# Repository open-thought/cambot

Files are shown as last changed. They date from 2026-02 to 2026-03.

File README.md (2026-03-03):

# CamBot

<p align="center">
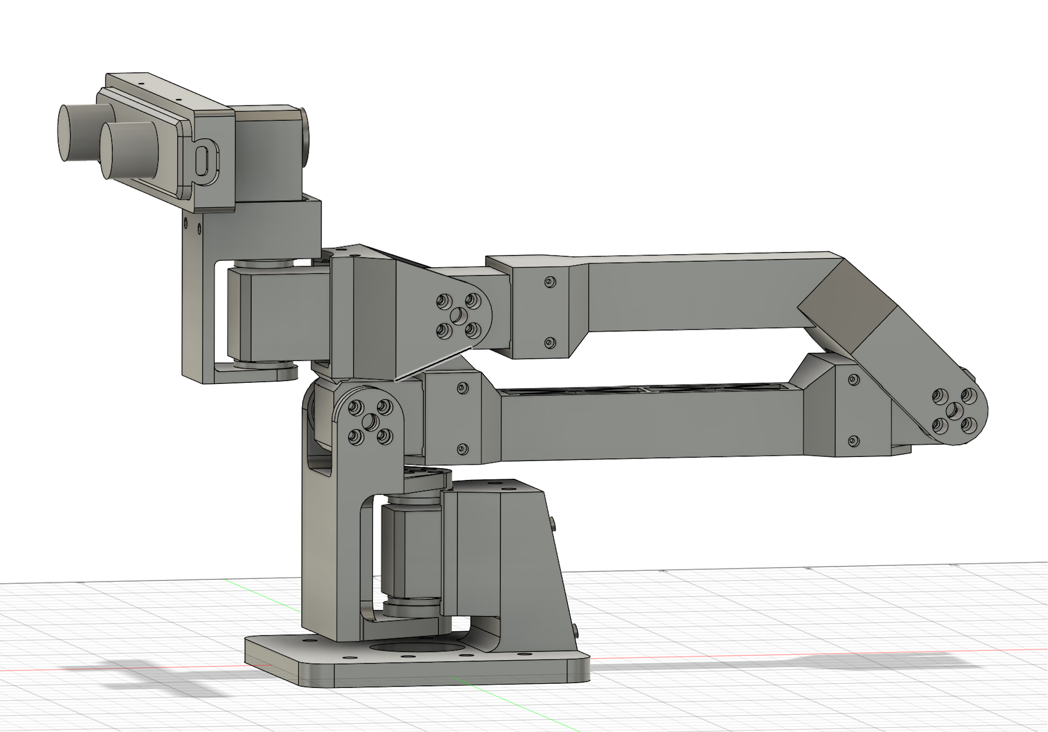
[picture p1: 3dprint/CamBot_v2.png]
CamBot
  
</p>

6-DOF camera arm for stereo vision, built with Feetech STS3215 servos and a ZED Mini stereo camera. Includes a VR teleop system using WebXR for real-time head tracking from any compatible VR headset (tested with Meta Quest 3).

**[Build & Assembly Guide](docs/BUILD_GUIDE.md)**

## Hardware

- **Body:** 7x 3D printed parts (PLA)
- **Servos:** 6x Feetech STS3215 (serial bus)
- **Camera:** [StereoLabs ZED Mini](https://www.stereolabs.com/en-de/store/products/zed-mini) (63mm baseline stereo)
- **Joints:** base_yaw, shoulder_pitch, elbow_pitch, wrist_pitch, wrist_yaw, camera_roll

## Project Structure

```
cambot/
  servo/              Shared servo communication layer
    constants.py      Register addresses, motor config, conversions
    protocol.py       Wire protocol (decode/encode, connect, EPROM helpers)
    controller.py     CamBotServo class, save/load calibration
  teleop/             VR teleop application
    app.py            Main entry point (TeleHead control loop)
    server.py         HTTPS + WebSocket server (aiohttp)
    ik_solver.py      IK solver (ikpy + URDF)
    capture.py        ZED Mini / fallback camera capture
    webrtc.py         WebRTC H.264 video track
    client/           WebXR stereo viewer (Three.js)
  tools/              CLI diagnostic and setup tools
    fix_servo_ids.py  Scan and assign servo IDs
    read_params.py    Register dump / read / write
    set_pid.py        Write tested PID parameters to servos
    debug_control.py  Debug TUI with IK visualization
    pid_tuning.py     PID auto-tuner
    visualize_urdf.py URDF visualization (viser)
calibration/          Saved positions and calibration data
urdf/                 URDF model and STL meshes
3dprint/              STL files for 3D printing (mm scale)
docs/                 Build guide, datasheets, and manuals
```

## Setup

Tested on Linux (Ubuntu 24.04). Requires [uv](https://docs.astral.sh/uv/getting-started/installation/) for Python environment and dependency management.

```bash
uv pip install -e .              # install cambot package (editable)
uv pip install -e ".[viz]"       # + URDF visualization (viser)
```

For ZED Mini support, install the [ZED SDK](https://www.stereolabs.com/en-de/developers/release) and the [ZED Python API](https://www.stereolabs.com/docs/development/python/install) (not available on PyPI).

## VR Teleop

Stream stereo video to a WebXR-compatible VR headset and control the robot arm with head tracking:

```bash
./run_teleop.sh                              # full mode
./run_teleop.sh --no-robot                   # camera streaming only
./run_teleop.sh --no-camera                  # robot control only
./run_teleop.sh --no-zed                     # use fallback camera
```

<details>
<summary>All options</summary>

```
usage: cambot-teleop [-h] [--port PORT] [--no-robot] [--no-camera] [--no-zed]
                     [--smoothing SMOOTHING] [--rate RATE]
                     [--max-joint-vel MAX_JOINT_VEL]
                     [--position-scale POSITION_SCALE]
                     [--max-pos-delta MAX_POS_DELTA]
                     [--workspace-bounds WORKSPACE_BOUNDS]
                     [--watchdog-timeout WATCHDOG_TIMEOUT]
                     [--resolution {vga,720p,1080p,2k}]
                     [--camera-fps CAMERA_FPS] [--jpeg-quality JPEG_QUALITY]
                     [--no-webrtc] [--server-port SERVER_PORT]
                     [--save-home] [--save-resting]
                     [--home HOME] [--resting RESTING]

  --port PORT               Robot serial port (default: /dev/ttyACM0)
  --no-robot                Run without robot
  --no-camera               Run without camera
  --no-zed                  Use fallback camera instead of ZED SDK
  --smoothing SMOOTHING     EMA smoothing (0=none, 0.99=max)
  --rate RATE               Control loop Hz
  --max-joint-vel MAX_JOINT_VEL
                            Max joint velocity rad/s (default: 20.0)
  --position-scale POSITION_SCALE
                            Scale factor for VR head translation (default: 1.0)
  --max-pos-delta MAX_POS_DELTA
                            Safety sphere radius in meters (default: 0.15, 0=disable)
  --workspace-bounds WORKSPACE_BOUNDS
                            Bounding box 'xmin,xmax,ymin,ymax,zmin,zmax' (meters)
  --watchdog-timeout WATCHDOG_TIMEOUT
                            Return to home after N seconds without VR pose (default: 3.0, 0=disable)
  --resolution {vga,720p,1080p,2k}
                            Camera resolution (default: 720p)
  --camera-fps CAMERA_FPS   Camera FPS (default: auto based on resolution)
  --jpeg-quality JPEG_QUALITY
                            JPEG encoding quality 1-100 (default: 85)
  --no-webrtc               Disable WebRTC, use WebSocket JPEG only
  --server-port SERVER_PORT HTTPS server port (default: 8080)
  --save-home               Save current position as home and exit
  --save-resting            Save current position as resting and exit
  --home HOME               Path to home_position.json
  --resting RESTING         Path to resting_position.json
```

</details>

The server prints an HTTPS URL in the terminal — open it in the headset browser, then enter VR.

```
============================================================
  CamBot TeleHead: https://192.168.0.103:8080
  Robot: connected on /dev/ttyACM0
  Camera: ZED Mini 720p@60fps q85
  WebRTC: enabled (H.264)
  Safety: watchdog=3.0s

  Press ENTER to home (capture neutral head position).
  Press P+ENTER to toggle position tracking (default: OFF).
  Press L+ENTER to lock/unlock robot (pause control).
  Press Ctrl+C to quit.
============================================================
```

### Controls

**Terminal (host PC):**

| Key | Action |
|-----|---|
| Enter | Home robot and calibrate neutral head pose |
| P + Enter | Toggle position tracking (orientation-only ↔ full 6-DOF) |
| L + Enter | Toggle pause (lock robot in place) |
| Ctrl+C | Quit (returns robot to resting pose) |

**VR controllers (WebXR gamepad):**

| Button | Action |
|---|---|
| A / X | Home and calibrate (soft recalibrate if already homed) |
| B / Y | Toggle position tracking |
| Right squeeze | Toggle pause |
| Left squeeze | Toggle HUD overlay |
| Right thumbstick click | Cycle resolution (VGA → 720p → 1080p → 2K) |
| Left thumbstick click | Toggle transport (WebRTC H.264 ↔ WebSocket JPEG) |

The robot automatically pauses and returns to home when the headset is removed, and resumes when put back on.

### Safety features

Position tracking mode has built-in safety limits:

- **Position delta sphere** (default 15cm): limits end-effector displacement from home. `--max-pos-delta 0.20` for 20cm, or `--max-pos-delta 0` to disable.
- **Workspace bounding box**: hard axis-aligned limits in robot frame. `--workspace-bounds xmin,xmax,ymin,ymax,zmin,zmax` (meters). Auto-disables the default sphere.
- **Pose watchdog** (default 3s): smoothly returns to home if VR data stops (headset removed, connection lost). `--watchdog-timeout 5.0` or `--watchdog-timeout 0` to disable.

Additional safety: EMA smoothing, velocity clamping (20 rad/s), FK validation, torque limiting (90%).

## Tools

All tools have shell script wrappers in the project root:

```bash
./run_fix_servo_ids.sh           # scan/set servo IDs
./run_read_params.sh             # register dump
./run_set_pid.sh                 # write tested PID values to servos
./run_debug_control.sh           # debug TUI with IK
./run_pid_tuning.sh              # PID auto-tuner
./run_visualize_urdf.sh          # URDF 3D viewer (browser)
```

Or run directly via entry points: `uv run cambot-debug-control`

## Dependencies

- Python 3.12+
- `feetech-servo-sdk` (servo communication, imported as `scservo_sdk`)
- `numpy`, `scipy`, `ikpy` (IK solver)
- `aiohttp`, `opencv-python`, `aiortc` (teleop server + video + WebRTC)
- Optional: `pyzed` (ZED SDK), `viser` (URDF viz)

## Acknowledgements

- The [TRLC-DK1 Leader](https://github.com/robot-learning-co/trlc-dk1) arm design by Robot Learning Co. served as inspiration for CamBot.
- The [SO-ARM100](https://github.com/TheRobotStudio/SO-ARM100) project by The Robot Studio — CamBot uses the same servo platform and controller board.
- Special thanks to [Autodesk](https://www.autodesk.com/) for providing Fusion for personal use.
- Special thanks to [FeeTech](https://www.feetechrc.com/) for their great servo motors — I wish I already had these as a kid. ;-)

## License

Apache 2.0 — see [LICENSE](LICENSE) for details.

If you build a CamBot or use this project in your work, I'd love to hear about it! A mention or link back is always appreciated. And if you get your CamBot running, please share a photo or video on [X/Twitter](https://x.com) — tag [@neurosp1ke](https://x.com/neurosp1ke) so I can see it!

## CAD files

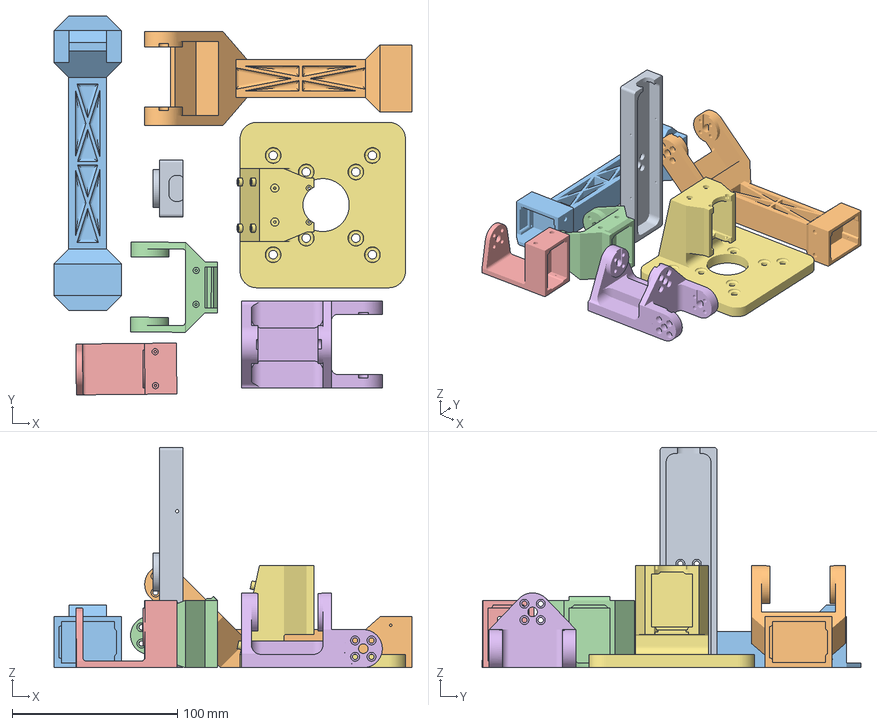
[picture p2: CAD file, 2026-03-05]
3dprint/CamBot_v2.3mf
216.4 x 229.1 x 133.2 mm
CamBot_ZedMiniMount_OffCenter.stl
CamBot_Link3_Thin.stl
CamBot_Link2_Thin.stl
CamBot_Link4.stl
CamBot_Link5.stl
CamBot_Link1.stl
CamBot_Baseplate.stl

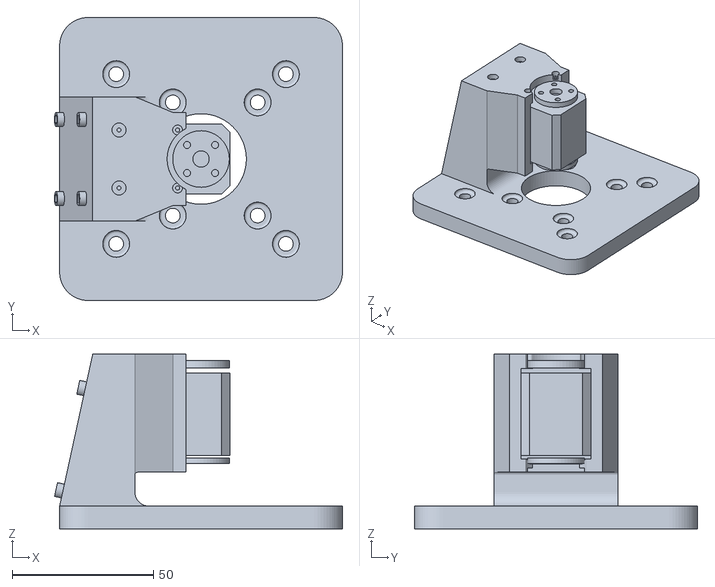
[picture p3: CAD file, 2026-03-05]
urdf/meshes/Baseplate.stl
101.8 x 100.0 x 61.7

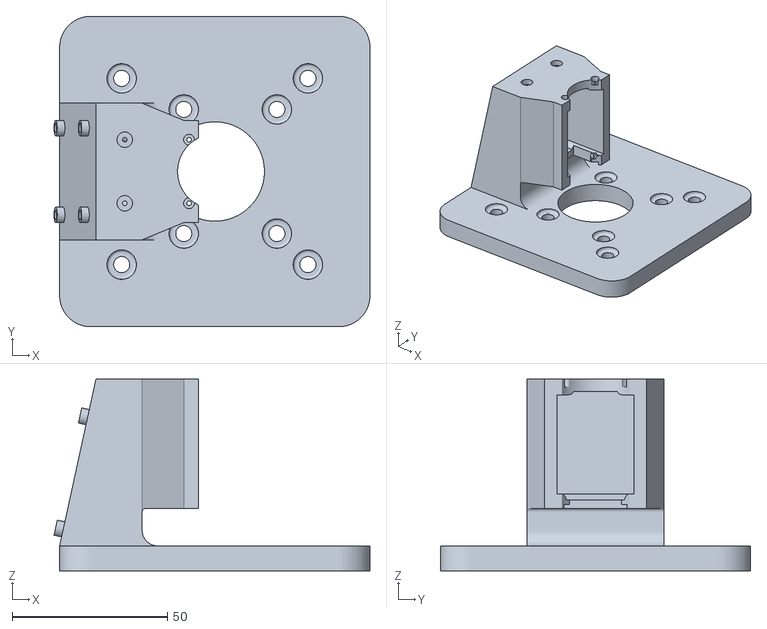
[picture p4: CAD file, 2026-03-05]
3dprint/CamBot_Baseplate.stl
101.8 x 100.0 x 61.7

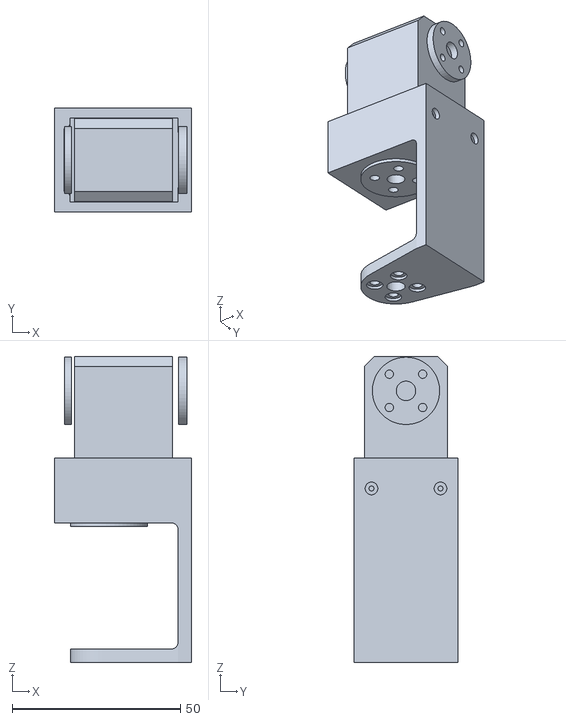
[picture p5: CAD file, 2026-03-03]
urdf/meshes/Link5.stl
40.7 x 30.8 x 90.9

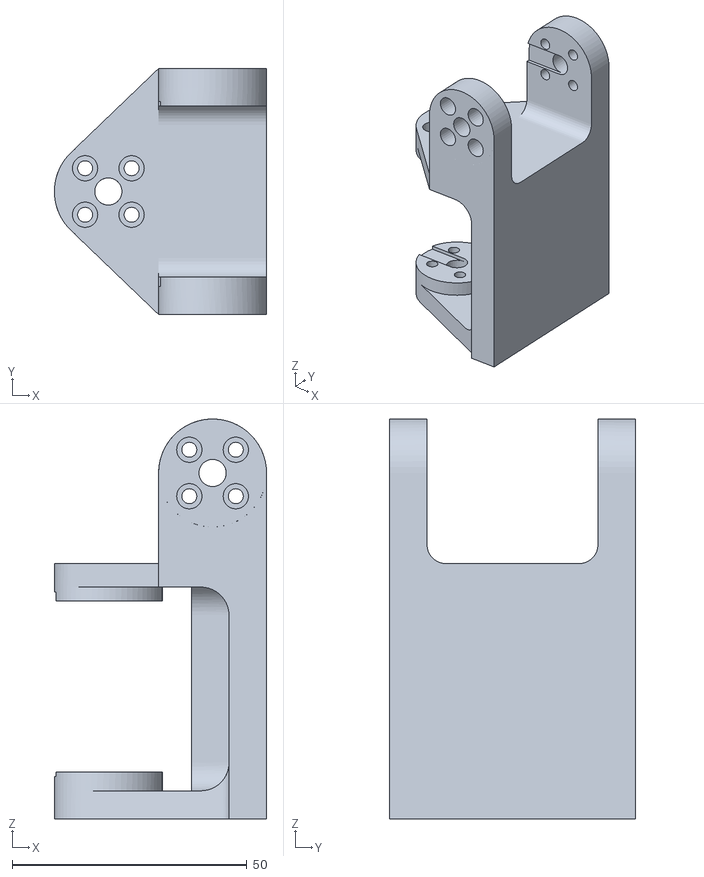
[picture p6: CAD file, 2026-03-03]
3dprint/CamBot_Link1.stl
45.2 x 52.4 x 85.2

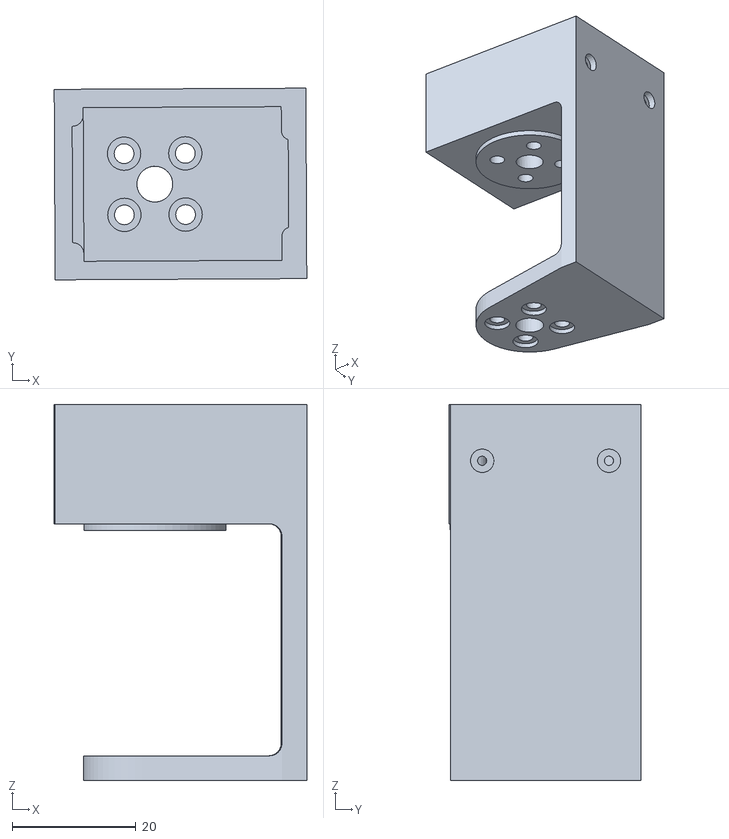
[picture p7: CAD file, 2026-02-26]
3dprint/CamBot_Link5.stl
40.9 x 31.0 x 60.8

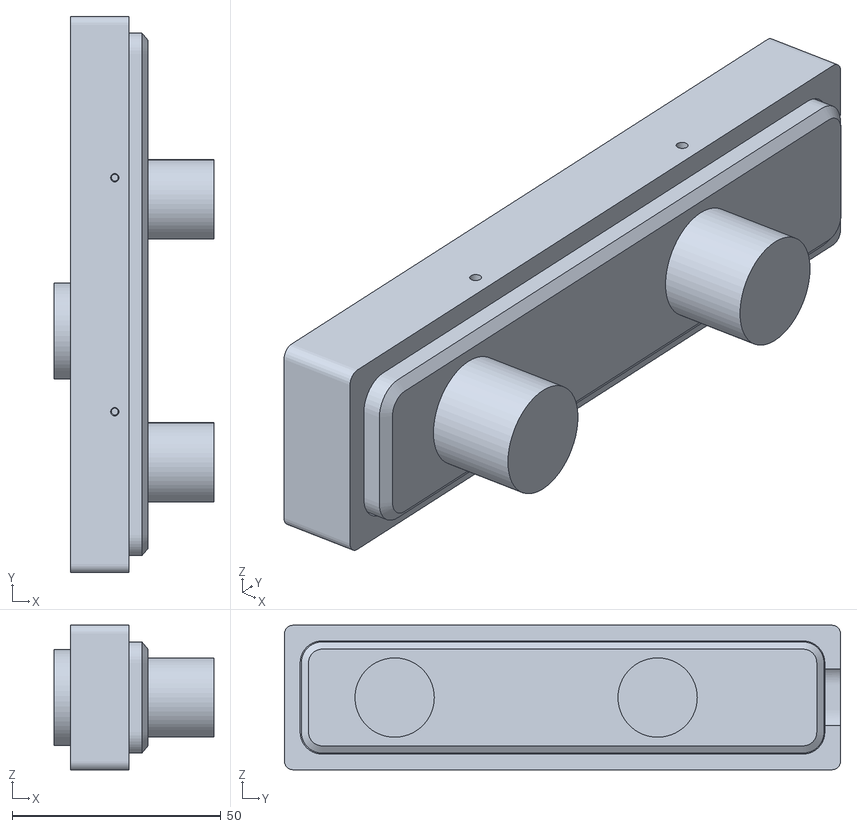
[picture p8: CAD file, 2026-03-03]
urdf/meshes/ZedMiniMount.stl
38.3 x 133.2 x 34.6

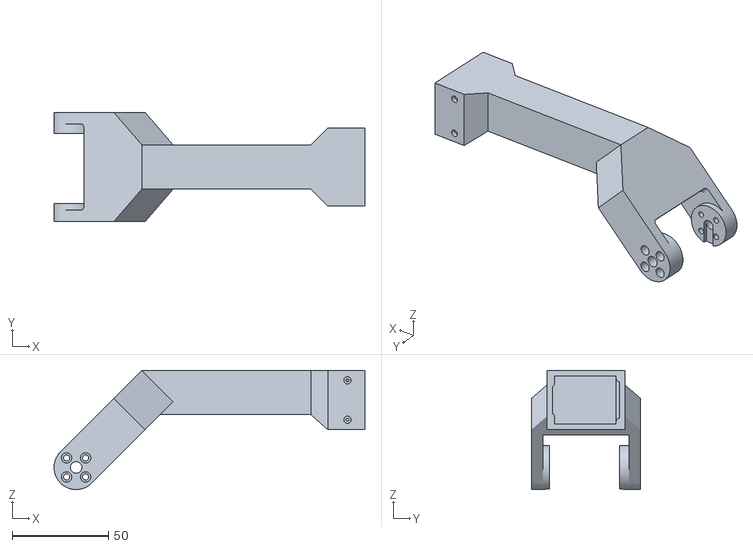
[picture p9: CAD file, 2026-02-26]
3dprint/CamBot_Link3.stl
161.6 x 56.7 x 61.9

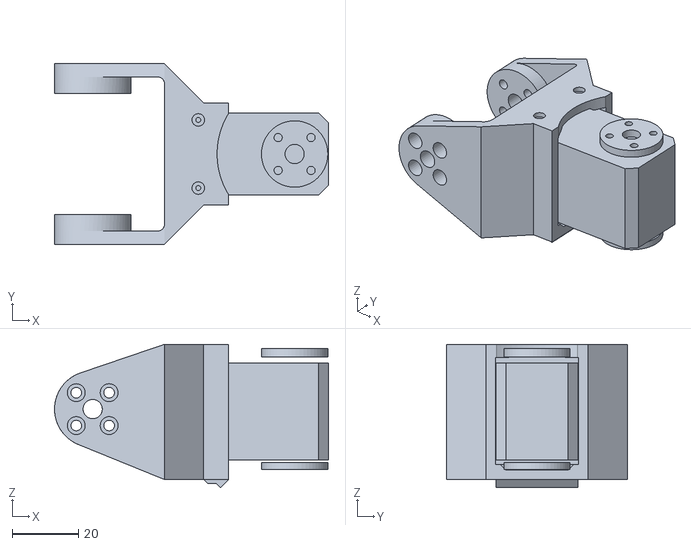
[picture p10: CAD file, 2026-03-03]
urdf/meshes/Link4.stl
82.5 x 54.4 x 43.1

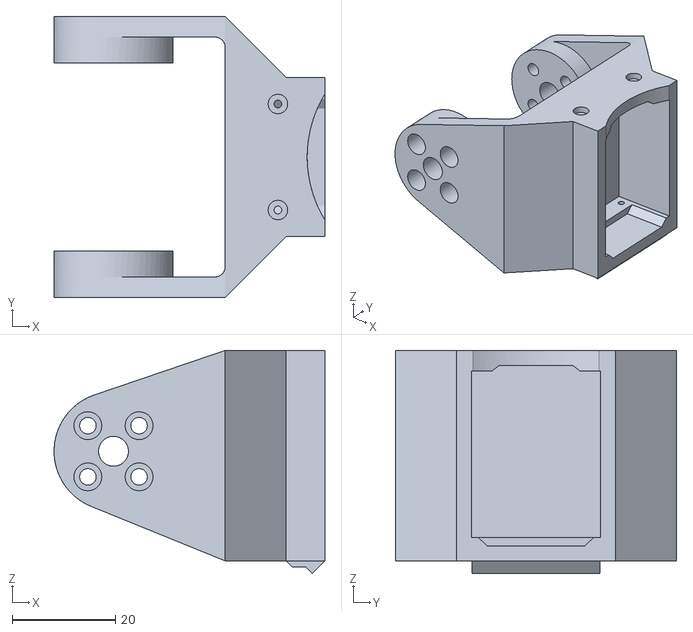
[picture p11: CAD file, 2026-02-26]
3dprint/CamBot_Link4.stl
52.4 x 54.4 x 43.1

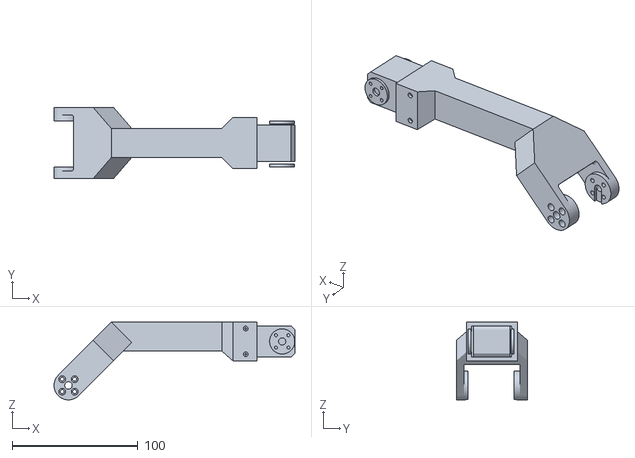
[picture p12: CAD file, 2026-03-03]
urdf/meshes/Link3.stl
191.7 x 56.7 x 61.9

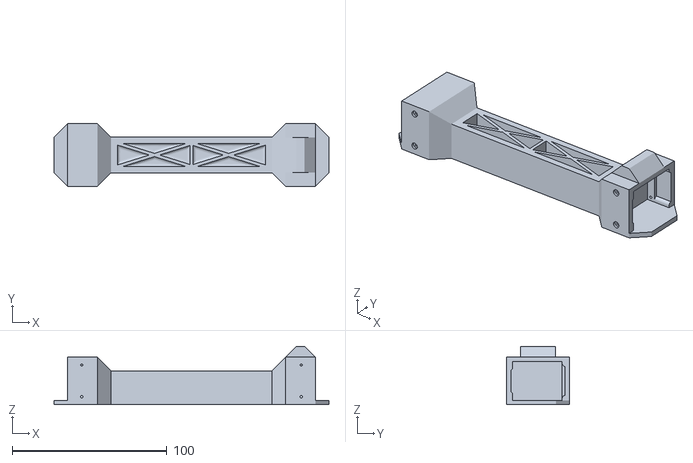
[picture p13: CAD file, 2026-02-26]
3dprint/CamBot_Link2.stl
177.9 x 40.7 x 37.8

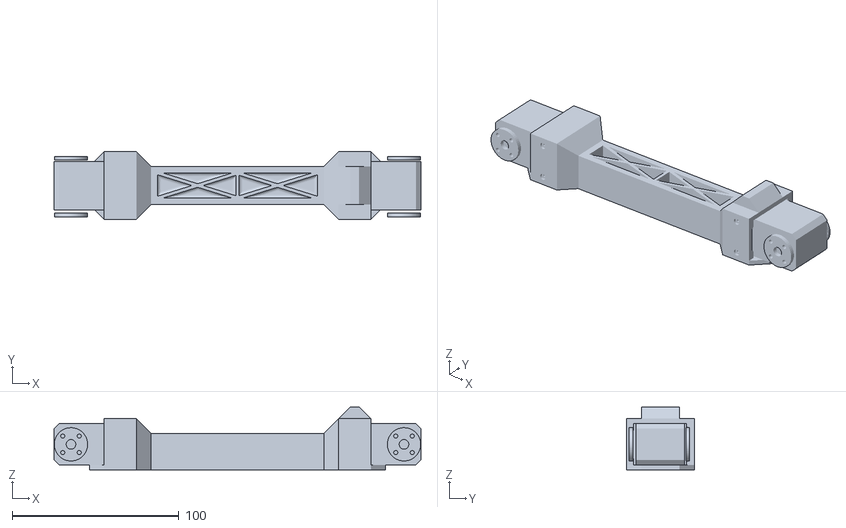
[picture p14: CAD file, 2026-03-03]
urdf/meshes/Link2.stl
220.4 x 40.7 x 37.8

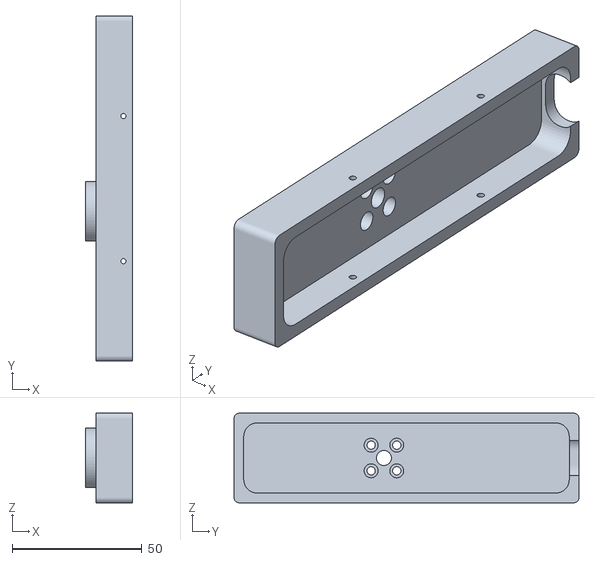
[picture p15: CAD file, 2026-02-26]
3dprint/CamBot_ZedMiniMount.stl
18.0 x 133.2 x 34.6

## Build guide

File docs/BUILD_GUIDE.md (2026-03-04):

# CamBot Build & Assembly Guide

## Parts List

| Part | Qty | Notes |
|---|-----|---|
| Feetech STS3215-C001 7.4V (1:345) | 3 | base_yaw, shoulder_pitch, elbow_pitch — high torque for structural joints |
| Feetech STS3215-C046 7.4V (1:147) | 3 | wrist_pitch, wrist_yaw, camera_roll — faster for orientation changes |
| Waveshare Bus Servo Adapter (A) | 1 | USB serial bus controller ([Amazon](https://amzn.eu/d/04b0u8LV)) |
| LEICKE Power supply 5V 4A 20W | 1 | Powers servo bus via adapter ([Amazon](https://amzn.eu/d/03hZC3xp)) |
| StereoLabs ZED Mini | 1 | USB 3.1 stereo camera, 63mm baseline ([Store](https://www.stereolabs.com/en-de/store/products/zed-mini)) |
| 3D printed parts | 7 | See printing section below |

For sourcing servos, the bus controller, power supply, USB cables, and screwdriver set, see the [SO-ARM100 repository](https://github.com/TheRobotStudio/SO-ARM100) — CamBot uses the same servo platform.

## 3D Printing

**Printer:** Bambu Lab A1 ([bambulab.com](https://bambulab.com/en/a1)) or similar FDM printer

**Filament:** eSUN PLA Basic 1.75mm (any rigid PLA works)

**Settings:**
- 25% infill (gyroid or grid)
- Tree supports (auto)
- 4 wall loops for rigidity

**Files:**
- Full Bambu Studio plate: `3dprint/CamBot_v2.3mf`
- Individual STLs in `3dprint/`:
  - `CamBot_Baseplate.stl`
  - `CamBot_Link1.stl` through `CamBot_Link5.stl`
  - `CamBot_ZedMiniMount.stl`

## Motor Configuration (Before Assembly)

### 1. Set Motor IDs

Connect only **one motor at a time** to the bus and assign IDs 1-6:

```bash
./run_fix_servo_ids.sh --set-id 1   # base_yaw
./run_fix_servo_ids.sh --set-id 2   # shoulder_pitch
./run_fix_servo_ids.sh --set-id 3   # elbow_pitch
./run_fix_servo_ids.sh --set-id 4   # wrist_pitch
./run_fix_servo_ids.sh --set-id 5   # wrist_yaw
./run_fix_servo_ids.sh --set-id 6   # camera_roll
```

### 2. Set PID & Torque Parameters

Connect all motors to the bus, then write the tested PID and torque values:

```bash
./run_set_pid.sh            # write recommended PID + torque settings
./run_set_pid.sh --dry-run  # preview values without writing
```

The recommended PID values (factory defaults are P=16, D=32, I=0):

| Joint | ID | Servo | P | D | I |
|---|---:|---|--:|--:|--:|
| base_yaw | 1 | C001 (1:345) | 24 | 48 | 0 |
| shoulder_pitch | 2 | C001 (1:345) | 32 | 16 | 0 |
| elbow_pitch | 3 | C001 (1:345) | 64 | 32 | 0 |
| wrist_pitch | 4 | C046 (1:147) | 48 | 32 | 0 |
| wrist_yaw | 5 | C046 (1:147) | 32 | 32 | 0 |
| camera_roll | 6 | C046 (1:147) | 25 | 32 | 0 |

These values were tuned for smooth VR teleop tracking. The C001 high-torque joints (base, shoulder, elbow) need different gains than the C046 fast joints (wrist, camera) due to their different gear ratios.

The script also writes torque protection settings:
- **Overload_Torque = 95** for motors 1-5 (factory default is 25). The factory value is too low — load-bearing joints (especially shoulder_pitch) constantly fight gravity, causing the servo to trip overload protection during normal operation. Setting it to 95 allows up to 95% of maximum torque before protection activates.
- **Max_Torque_Limit = 500** (50%) for camera_roll — no need for full torque on camera rotation.

A full reference dump of all register values is available in [`docs/reference_params.txt`](reference_params.txt).

### 3. Verify

```bash
./run_read_params.sh        # full register dump — check PID, ID, mode
```

## Assembly

1. Label each servo with its ID (1-6) before assembly — they are indistinguishable once mounted.
2. Assemble from base to camera: Baseplate -> Link1 -> Link2 -> Link3 -> Link4 -> Link5 -> ZedMiniMount.
3. Route servo cables through the links. Daisy-chain all servos on the same bus.
4. Apply medium-strength threadlocker (e.g. Loctite 243) to the servo flange screws — vibrations will loosen them over time.
5. Mount the ZED Mini camera on the top link using the printed mount.

## Calibration

After assembly, calibrate the two reference poses:

### 1. URDF Zero (Resting) Pose

Position the arm in the resting pose shown below. This defines the URDF zero reference for the IK solver.

CamBot URDF zero pose

```bash
./run_teleop.sh --save-resting
# or use debug_control: ./run_debug_control.sh then press Z
```

### 2. Home Pose

Move the arm to the starting camera position for VR teleop (where the camera faces forward at a comfortable viewing angle). The photo below shows an example home pose used during testing:

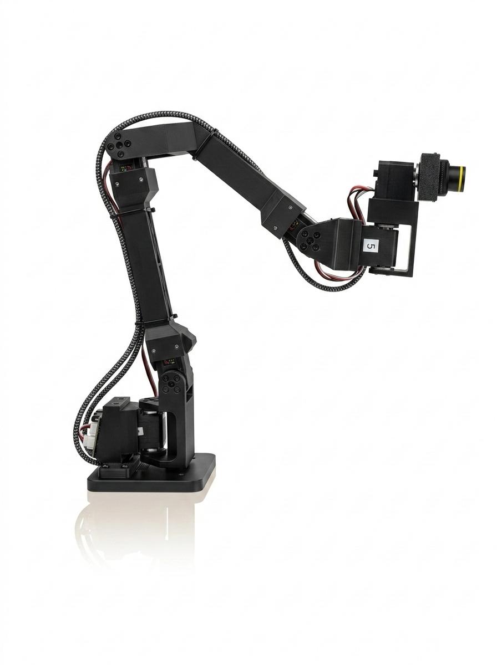
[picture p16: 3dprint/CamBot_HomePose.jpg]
CamBot home pose example


```bash
./run_teleop.sh --save-home
# or use debug_control: ./run_debug_control.sh then press H
```

## Running

```bash
./run_teleop.sh                    # full VR teleop (robot + camera + WebRTC)
./run_teleop.sh --no-robot         # camera streaming only (no servos)
./run_teleop.sh --no-camera        # robot control only (no video)
./run_teleop.sh --no-zed           # use fallback USB camera
```

Open the displayed HTTPS URL in the headset browser, enter VR, then press Enter in the terminal to calibrate the neutral head position.

## PID Tuning (Optional, Advanced)

The default PID values set by `run_set_pid.sh` work well for general use. If you want to tune for your specific build (different filament or payload), there are two approaches:

### Interactive tuning with debug_control

```bash
./run_debug_control.sh
```

Switch to PID mode (press `P` in the TUI) to adjust P, D, and I gains per joint in real time while watching the servo response. This is the best way to get a feel for how each parameter affects tracking behavior — you can command step moves and immediately see overshoot, settling time, and steady-state error.

### Automated tuning (experimental)

> **Warning:** Automated tuning is experimental and puts the hardware under stress. It commands rapid step moves at various gain levels, which can cause jerky motion and high transient loads on the servos and 3D printed parts. Supervise the robot during tuning and be ready to kill the script if anything sounds or looks wrong.

```bash
uv run cambot-pid-tuning --capture-poses           # capture test poses first
uv run cambot-pid-tuning --joints shoulder_pitch    # tune a specific joint
uv run cambot-pid-tuning --verbose                  # tune all joints with detailed output
uv run cambot-pid-tuning --restore-factory          # reset to factory PID defaults
```

Runs automated step-response tests and searches for gains that minimize overshoot and settling time.

If you find better PID values for your build, please share them by [opening a GitHub issue](https://github.com/open-thought/cambot/issues).

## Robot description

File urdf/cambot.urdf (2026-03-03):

<?xml version="1.0" encoding="utf-8"?>
<robot name="CamBot">

  <!-- ==================== Materials ==================== -->
  <material name="dark_grey">
    <color rgba="0.3 0.3 0.3 1.0"/>
  </material>
  <material name="light_grey">
    <color rgba="0.6 0.6 0.6 1.0"/>
  </material>
  <material name="black">
    <color rgba="0.1 0.1 0.1 1.0"/>
  </material>

  <!-- ==================== Links ==================== -->

  <!-- Baseplate: world origin (0, 0, 0) -->
  <link name="base_link">
    <visual>
      <origin xyz="0 0 0" rpy="0 0 0"/>
      <geometry>
        <mesh filename="meshes/Baseplate.stl"/>
      </geometry>
      <material name="dark_grey"/>
    </visual>
  </link>

  <!-- Link1: world pos (0, 0, 0.03820) -->
  <link name="link1">
    <visual>
      <origin xyz="0 0 -0.03820" rpy="0 0 0"/>
      <geometry>
        <mesh filename="meshes/Link1.stl"/>
      </geometry>
      <material name="light_grey"/>
    </visual>
  </link>

  <!-- Link2: world pos (0.02220, 0, 0.08370) -->
  <link name="link2">
    <visual>
      <origin xyz="-0.02220 0 -0.08370" rpy="0 0 0"/>
      <geometry>
        <mesh filename="meshes/Link2.stl"/>
      </geometry>
      <material name="dark_grey"/>
    </visual>
  </link>

  <!-- Link3: world pos (-0.17780, 0, 0.08370) -->
  <link name="link3">
    <visual>
      <origin xyz="0.17780 0 -0.08370" rpy="0 0 0"/>
      <geometry>
        <mesh filename="meshes/Link3.stl"/>
      </geometry>
      <material name="light_grey"/>
    </visual>
  </link>

  <!-- Link4: world pos (-0.00780, 0, 0.11870) -->
  <link name="link4">
    <visual>
      <origin xyz="0.00780 0 -0.11870" rpy="0 0 0"/>
      <geometry>
        <mesh filename="meshes/Link4.stl"/>
      </geometry>
      <material name="dark_grey"/>
    </visual>
  </link>

  <!-- Link5: world pos (0.05300, 0, 0.11870) -->
  <link name="link5">
    <visual>
      <origin xyz="-0.05300 0 -0.11870" rpy="0 0 0"/>
      <geometry>
        <mesh filename="meshes/Link5.stl"/>
      </geometry>
      <material name="light_grey"/>
    </visual>
  </link>

  <!-- ZED Mini mount: world pos (0.05800, 0, 0.17720) -->
  <link name="zed_mini_mount">
    <visual>
      <origin xyz="-0.05800 0 -0.17720" rpy="0 0 0"/>
      <geometry>
        <mesh filename="meshes/ZedMiniMount.stl"/>
      </geometry>
      <material name="black"/>
    </visual>
  </link>

  <!-- Camera links (no visual geometry, just reference frames) -->
  <link name="right_camera_link"/>
  <link name="left_camera_link"/>
  <link name="right_camera_optical_frame"/>
  <link name="left_camera_optical_frame"/>

  <!-- ==================== Joints ==================== -->

  <!-- Joint 1: base_link -> link1, vertical rotation (Z axis) -->
  <!-- Relative: (0, 0, 0.03820) - (0, 0, 0) = (0, 0, 0.03820) -->
  <joint name="base_yaw" type="revolute">
    <parent link="base_link"/>
    <child link="link1"/>
    <origin xyz="0 0 0.03820" rpy="0 0 0"/>
    <axis xyz="0 0 -1"/>
    <limit lower="-1.2747" upper="1.3346" effort="1.5" velocity="3.0"/>
  </joint>

  <!-- Joint 2: link1 -> link2, horizontal rotation (Y axis) -->
  <!-- Relative: (0.02220, 0, 0.08370) - (0, 0, 0.03820) = (0.02220, 0, 0.04550) -->
  <joint name="shoulder_pitch" type="revolute">
    <parent link="link1"/>
    <child link="link2"/>
    <origin xyz="0.02220 0 0.04550" rpy="0 0 0"/>
    <axis xyz="0 -1 0"/>
    <limit lower="-3.4392" upper="0.0936" effort="1.5" velocity="3.0"/>
  </joint>

  <!-- Joint 3: link2 -> link3, horizontal rotation (Y axis) -->
  <!-- Relative: (-0.17780, 0, 0.08370) - (0.02220, 0, 0.08370) = (-0.20000, 0, 0) -->
  <joint name="elbow_pitch" type="revolute">
    <parent link="link2"/>
    <child link="link3"/>
    <origin xyz="-0.20000 0 0" rpy="0 0 0"/>
    <axis xyz="0 1 0"/>
    <limit lower="-4.2599" upper="0.0353" effort="1.5" velocity="3.0"/>
  </joint>

  <!-- Joint 4: link3 -> link4, horizontal rotation (Y axis) -->
  <!-- Relative: (-0.00780, 0, 0.11870) - (-0.17780, 0, 0.08370) = (0.17000, 0, 0.03500) -->
  <joint name="wrist_pitch" type="revolute">
    <parent link="link3"/>
    <child link="link4"/>
    <origin xyz="0.17000 0 0.03500" rpy="0 0 0"/>
    <axis xyz="0 1 0"/>
    <limit lower="-1.9666" upper="1.6782" effort="1.5" velocity="3.0"/>
  </joint>

  <!-- Joint 5: link4 -> link5, vertical rotation (Z axis) -->
  <!-- Relative: (0.05300, 0, 0.11870) - (-0.00780, 0, 0.11870) = (0.06080, 0, 0) -->
  <joint name="wrist_yaw" type="revolute">
    <parent link="link4"/>
    <child link="link5"/>
    <origin xyz="0.06080 0 0" rpy="0 0 0"/>
    <axis xyz="0 0 -1"/>
    <limit lower="-1.8699" upper="1.8438" effort="1.5" velocity="3.0"/>
  </joint>

  <!-- Joint 6: link5 -> zed_mini_mount, rotation around X axis -->
  <!-- Relative: (0.05800, 0, 0.17720) - (0.05300, 0, 0.11870) = (0.00500, 0, 0.05850) -->
  <joint name="camera_roll" type="revolute">
    <parent link="link5"/>
    <child link="zed_mini_mount"/>
    <origin xyz="0.00500 0 0.05850" rpy="0 0 0"/>
    <axis xyz="-1 0 0"/>
    <limit lower="-3.2030" upper="3.1339" effort="1.5" velocity="3.0"/>
  </joint>

  <!-- ==================== Camera Joints (fixed) ==================== -->

  <!-- Right camera: world (0.114507, -0.03150, 0.177188) relative to zed_mount (0.05800, 0, 0.17720) -->
  <joint name="right_camera_joint" type="fixed">
    <parent link="zed_mini_mount"/>
    <child link="right_camera_link"/>
    <origin xyz="0.056507 -0.03150 0" rpy="0 0 0"/>
  </joint>

  <!-- Left camera: world (0.114507, 0.03150, 0.177188) relative to zed_mount (0.05800, 0, 0.17720) -->
  <joint name="left_camera_joint" type="fixed">
    <parent link="zed_mini_mount"/>
    <child link="left_camera_link"/>
    <origin xyz="0.056507 0.03150 0" rpy="0 0 0"/>
  </joint>

  <!-- Optical frames: rotated so +Z = forward (optical axis), +X = right, +Y = down -->
  <joint name="right_camera_optical_joint" type="fixed">
    <parent link="right_camera_link"/>
    <child link="right_camera_optical_frame"/>
    <origin xyz="0 0 0" rpy="-1.5707963267948966 0 -1.5707963267948966"/>
  </joint>

  <joint name="left_camera_optical_joint" type="fixed">
    <parent link="left_camera_link"/>
    <child link="left_camera_optical_frame"/>
    <origin xyz="0 0 0" rpy="-1.5707963267948966 0 -1.5707963267948966"/>
  </joint>

</robot>

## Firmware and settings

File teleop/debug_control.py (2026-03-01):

#!/usr/bin/env python3
"""Debug Control TUI for StereoBot.

Two modes (Tab to switch):
  Joint Mode:    Select joint (1-6/Up/Down), move with Left/Right, +/- step size
  Cartesian Mode: WASD=X/Y, QE=Z, IJKL=pitch/yaw, UO=roll

Shared controls:
  t/T  Toggle torque (selected / all)
  h    Smooth move to home position
  0    Smooth move to URDF zero (resting position)
  Tab  Switch mode
  q/ESC Quit (ESC only in Cartesian mode, since Q=Z-up)

Usage:
    python teleop/debug_control.py
    python teleop/debug_control.py --port /dev/ttyACM0
"""

from __future__ import annotations

import argparse
import curses
import json
import math
import os
import sys
import time

import numpy as np
import scservo_sdk as scs

# Add parent to path for imports
sys.path.insert(0, os.path.dirname(__file__))

from robot_control import (
    StereoBotServo,
    decode_sm,
    encode_sm,
    STEPS_PER_REV,
    STEPS_TO_RAD,
    RAD_TO_STEPS,
    POS_SIGN_BIT,
    ADDR_TORQUE_ENABLE,
    ADDR_GOAL_POSITION,
    ADDR_PRESENT_POSITION,
)
from ik_solver import StereoBotIK, JOINT_NAMES

# --- Register addresses for extended telemetry ---
ADDR_P_COEFFICIENT = 21   # 1 byte, EPROM
ADDR_D_COEFFICIENT = 22   # 1 byte, EPROM
ADDR_I_COEFFICIENT = 23   # 1 byte, EPROM
ADDR_LOCK = 55            # 1 byte, SRAM (0=EPROM unlocked)
ADDR_PRESENT_SPEED = 58   # 2 bytes, sign-magnitude bit 15
ADDR_PRESENT_LOAD = 60    # 2 bytes, sign-magnitude bit 10
ADDR_PRESENT_VOLTAGE = 62 # 1 byte, x0.1V
ADDR_PRESENT_TEMPERATURE = 63  # 1 byte, Celsius
ADDR_PRESENT_CURRENT = 69 # 2 bytes, unsigned, mA

# Extended sync read: addr 56, 15 bytes covers position(2) + speed(2) + load(2) + voltage(1) + temp(1) + pad(5) + current(2)
# But current is at addr 69 which is 56+13, so we need 15 bytes: 69-56+2 = 15
SYNC_READ_START = 56
SYNC_READ_LEN = 15  # covers addr 56-70

# Calibration file paths
CAL_DIR = os.path.join(os.path.dirname(__file__), "..", "calibration")
HOME_PATH = os.path.join(CAL_DIR, "home_position.json")
RESTING_PATH = os.path.join(CAL_DIR, "resting_position.json")

MODE_JOINT = 0
MODE_CARTESIAN = 1
MODE_PID = 2
NUM_MODES = 3
MODE_NAMES = ["JOINT", "CARTESIAN/IK", "PID TUNING"]

PID_COEFF_NAMES = ["P", "D", "I"]
PID_COEFF_ADDRS = [ADDR_P_COEFFICIENT, ADDR_D_COEFFICIENT, ADDR_I_COEFFICIENT]
PID_FACTORY_DEFAULTS = (16, 32, 0)  # STS3215 factory P, D, I



def load_json(path: str) -> dict | None:
    if not os.path.exists(path):
        return None
    with open(path) as f:
        return json.load(f)


def rodrigues_rotate(mat4: np.ndarray, axis: np.ndarray, angle_rad: float) -> np.ndarray:
    """Apply incremental rotation via Rodrigues formula to a 4x4 transform.

    Rotates the orientation (upper-left 3x3) of mat4 around `axis` (in world frame)
    by `angle_rad`. Position is unchanged.
    """
    result = mat4.copy()
    axis = axis / np.linalg.norm(axis)
    K = np.array([
        [0, -axis[2], axis[1]],
        [axis[2], 0, -axis[0]],
        [-axis[1], axis[0], 0],
    ])
    c = math.cos(angle_rad)
    s = math.sin(angle_rad)
    R_inc = np.eye(3) * c + s * K + (1 - c) * np.outer(axis, axis)
    result[:3, :3] = R_inc @ mat4[:3, :3]
    return result


class DebugControlTUI:
    """Curses-based debug control interface."""

    def __init__(self, port: str = "/dev/ttyACM0", baudrate: int = 1_000_000, servo_time_profile: bool = False):
        self.port = port
        self.baudrate = baudrate
        self.servo_time_profile = servo_time_profile
        self.servo: StereoBotServo | None = None
        self.ik: StereoBotIK | None = None

        # Mode
        self.mode = MODE_JOINT
        self.selected_joint = 0  # index into JOINT_NAMES
        self.joint_step = 20     # steps

        # Cartesian mode
        self.cart_trans_step = 5.0   # mm
        self.cart_rot_step = 2.0     # degrees
        self.target_4x4: np.ndarray | None = None
        self.workspace_min = np.full(3, np.inf)
        self.workspace_max = np.full(3, -np.inf)
        self.ik_success = True
        self.last_ik_angles: dict[str, float] = {}

        # Telemetry
        self.goal_positions: dict[str, int] = {}    # tracked locally
        self.actual_positions: dict[str, int] = {}
        self.speeds: dict[str, int] = {}
        self.loads: dict[str, int] = {}
        self.voltages: dict[str, float] = {}
        self.temperatures: dict[str, int] = {}
        self.currents: dict[str, int] = {}

        # PID coefficients (read from EPROM)
        self.pid: dict[str, tuple[int, int, int]] = {}  # name -> (P, D, I)

        # PID tuning state
        self.pid_selected_coeff = 0  # 0=P, 1=D, 2=I
        self.pid_step = 1            # adjustment step size

        # Torque state
        self.torque_on = False

        # Calibration data
        self.home_raw = load_json(HOME_PATH)
        self.resting_raw = load_json(RESTING_PATH)

        # Status message
        self.status_msg = ""
        self.status_time = 0.0

        # Extended GroupSyncRead
        self._ext_sync_read: scs.GroupSyncRead | None = None

    def connect(self):
        """Connect to servos and IK solver."""
        urdf_zero = self.resting_raw
        self.servo = StereoBotServo.connect(self.port, self.baudrate, urdf_zero=urdf_zero)

        # Set up extended GroupSyncRead (addr 56, 15 bytes)
        self._ext_sync_read = scs.GroupSyncRead(
            self.servo.ph, self.servo.pkt, SYNC_READ_START, SYNC_READ_LEN
        )
        for name in JOINT_NAMES:
            mid = StereoBotServo.MOTOR_IDS[name]
            self._ext_sync_read.addParam(mid)

        # Read PID coefficients (once)
        self._read_pid_coefficients()

        # Read initial positions as goals
        raw = self.servo.read_raw_positions()
        self.goal_positions = dict(raw)
        self.actual_positions = dict(raw)

        # Init IK solver
        self.ik = StereoBotIK()

        # Init Cartesian target from current FK
        if self.resting_raw:
            angles = self.servo.raw_to_relative(raw)
            self.target_4x4 = self.ik.forward_kinematics(angles)

    def _read_pid_coefficients(self):
        """Read P, D, I coefficients from EPROM for all motors."""
        for name in JOINT_NAMES:
            mid = StereoBotServo.MOTOR_IDS[name]
            p_val, _, _ = self.servo.pkt.read1ByteTxRx(self.servo.ph, mid, ADDR_P_COEFFICIENT)
            d_val, _, _ = self.servo.pkt.read1ByteTxRx(self.servo.ph, mid, ADDR_D_COEFFICIENT)
            i_val, _, _ = self.servo.pkt.read1ByteTxRx(self.servo.ph, mid, ADDR_I_COEFFICIENT)
            self.pid[name] = (p_val, d_val, i_val)

    def _write_pid_coefficient(self, name: str, coeff_idx: int, value: int):
        """Write a single PID coefficient to EPROM for one motor.

        EPROM write sequence: torque off → Lock=0 → write → Lock=1.
        Torque is re-enabled afterward if self.torque_on is True.
        """
        value = max(0, min(255, value))
        mid = StereoBotServo.MOTOR_IDS[name]
        ph, pkt = self.servo.ph, self.servo.pkt
        addr = PID_COEFF_ADDRS[coeff_idx]

        # Save/restore blocking timeout for reliable EPROM writes
        old_timeout = ph.ser.write_timeout
        ph.ser.write_timeout = None

        try:
            # 1. Torque off
            pkt.write1ByteTxRx(ph, mid, ADDR_TORQUE_ENABLE, 0)
            time.sleep(0.01)
            # 2. Unlock EPROM
            pkt.write1ByteTxRx(ph, mid, ADDR_LOCK, 0)
            time.sleep(0.01)
            # 3. Write coefficient
            pkt.write1ByteTxRx(ph, mid, addr, value)
            time.sleep(0.01)
            # 4. Lock EPROM
            pkt.write1ByteTxRx(ph, mid, ADDR_LOCK, 1)
            time.sleep(0.01)
            # 5. Re-enable torque if it was on
            if self.torque_on:
                pkt.write1ByteTxRx(ph, mid, ADDR_TORQUE_ENABLE, 1)
            # 6. Flush rx buffer — EPROM writes can leave stale bytes
            time.sleep(0.01)
            ph.ser.reset_input_buffer()
        finally:
            ph.ser.write_timeout = old_timeout

        # Update local state
        p, d, i = self.pid.get(name, (0, 0, 0))
        vals = [p, d, i]
        vals[coeff_idx] = value
        self.pid[name] = tuple(vals)

    def _write_pid_all_motors(self, coeff_idx: int, value: int):
        """Write a PID coefficient to all motors."""
        for name in JOINT_NAMES:
            self._write_pid_coefficient(name, coeff_idx, value)

    def _copy_pid_to_all(self, source_name: str):
        """Copy all PID values from source joint to all other joints."""
        p, d, i = self.pid.get(source_name, PID_FACTORY_DEFAULTS)
        for coeff_idx, val in enumerate((p, d, i)):
            for name in JOINT_NAMES:
                if name != source_name:
                    self._write_pid_coefficient(name, coeff_idx, val)

    def _read_extended_telemetry(self):
        """Read position, speed, load, voltage, temp, current for all motors in one packet."""
        old_timeout = self.servo.ph.ser.write_timeout
        self.servo.ph.ser.write_timeout = None

        try:
            comm_result = self._ext_sync_read.txRxPacket()
            if comm_result != scs.COMM_SUCCESS:
                return

            for name in JOINT_NAMES:
                mid = StereoBotServo.MOTOR_IDS[name]
                if not self._ext_sync_read.isAvailable(mid, ADDR_PRESENT_POSITION, 2):
                    continue

                # Position (addr 56, 2 bytes, sign-magnitude bit 15)
                raw_pos = self._ext_sync_read.getData(mid, ADDR_PRESENT_POSITION, 2)
                self.actual_positions[name] = decode_sm(raw_pos, POS_SIGN_BIT)

                # Speed (addr 58, 2 bytes, sign-magnitude bit 15)
                if self._ext_sync_read.isAvailable(mid, ADDR_PRESENT_SPEED, 2):
                    raw_spd = self._ext_sync_read.getData(mid, ADDR_PRESENT_SPEED, 2)
                    self.speeds[name] = decode_sm(raw_spd, 15)

                # Load (addr 60, 2 bytes, sign-magnitude bit 10)
                if self._ext_sync_read.isAvailable(mid, ADDR_PRESENT_LOAD, 2):
                    raw_load = self._ext_sync_read.getData(mid, ADDR_PRESENT_LOAD, 2)
                    self.loads[name] = decode_sm(raw_load, 10)

                # Voltage (addr 62, 1 byte, x0.1V)
                if self._ext_sync_read.isAvailable(mid, ADDR_PRESENT_VOLTAGE, 1):
                    raw_v = self._ext_sync_read.getData(mid, ADDR_PRESENT_VOLTAGE, 1)
                    self.voltages[name] = round(raw_v * 0.1, 1)

                # Temperature (addr 63, 1 byte)
                if self._ext_sync_read.isAvailable(mid, ADDR_PRESENT_TEMPERATURE, 1):
                    self.temperatures[name] = self._ext_sync_read.getData(mid, ADDR_PRESENT_TEMPERATURE, 1)

                # Current (addr 69, 2 bytes, unsigned mA)
                if self._ext_sync_read.isAvailable(mid, ADDR_PRESENT_CURRENT, 2):
                    self.currents[name] = self._ext_sync_read.getData(mid, ADDR_PRESENT_CURRENT, 2)
        finally:
            self.servo.ph.ser.write_timeout = old_timeout

    def _set_status(self, msg: str):
        self.status_msg = msg
        self.status_time = time.monotonic()

    def _move_joint_step(self, direction: int):
        """Move selected joint by step in given direction (+1 or -1)."""
        name = JOINT_NAMES[self.selected_joint]
        current_goal = self.goal_positions.get(name, self.actual_positions.get(name, 2048))
        new_goal = max(0, min(4095, current_goal + direction * self.joint_step))
        self.goal_positions[name] = new_goal
        self.servo.write_raw_positions({name: new_goal})
        self._set_status(f"{name}: {current_goal} -> {new_goal} (step={self.joint_step})")

    def _move_cartesian(self, axis: str, direction: float):
        """Move Cartesian target along axis by step."""
        if self.target_4x4 is None:
            self._set_status("No Cartesian target (need resting_position.json)")
            return

        step_m = self.cart_trans_step / 1000.0  # mm to meters
        step_rad = math.radians(self.cart_rot_step)

        t = self.target_4x4

        if axis == "x":
            t[:3, 3] += np.array([1, 0, 0]) * direction * step_m
        elif axis == "y":
            t[:3, 3] += np.array([0, 1, 0]) * direction * step_m
        elif axis == "z":
            t[:3, 3] += np.array([0, 0, 1]) * direction * step_m
        elif axis == "pitch":
            t = rodrigues_rotate(t, np.array([0, 1, 0]), direction * step_rad)
        elif axis == "yaw":
            t = rodrigues_rotate(t, np.array([0, 0, 1]), direction * step_rad)
        elif axis == "roll":
            t = rodrigues_rotate(t, np.array([1, 0, 0]), direction * step_rad)

        self.target_4x4 = t

        # Update workspace bounds
        pos = t[:3, 3]
        self.workspace_min = np.minimum(self.workspace_min, pos)
        self.workspace_max = np.maximum(self.workspace_max, pos)

        # Solve IK with warm-start
        q_init = self.last_ik_angles if self.last_ik_angles else None
        angles, success = self.ik.solve(t, q_init)
        self.ik_success = success
        self.last_ik_angles = angles

        if success or not q_init:
            # Convert to raw and command servos
            raw = {}
            for name, rad in angles.items():
                zero = self.servo._zero_raw.get(name, 0)
                raw[name] = max(0, min(4095, zero + int(round(rad * RAD_TO_STEPS))))
            self.goal_positions.update(raw)
            self.servo.write_raw_positions(raw)

        label = axis.upper()
        self._set_status(f"IK {'OK' if success else 'FAIL'} | {label} {direction:+.0f} | pos=[{pos[0]*1000:.0f}, {pos[1]*1000:.0f}, {pos[2]*1000:.0f}]mm")

    def _smooth_move_to(self, target_raw: dict[str, int], label: str):
        """Smooth move to a target position."""
        self._set_status(f"Moving to {label}...")
        self.servo.set_torque(True)
        self.torque_on = True
        self.servo.move_to_raw_position(target_raw, duration=1.5, use_servo_time_profile=self.servo_time_profile)
        self.goal_positions.update(target_raw)

        # Update Cartesian target if in IK mode
        if self.ik and self.resting_raw:
            angles = self.servo.raw_to_relative(target_raw)
            self.target_4x4 = self.ik.forward_kinematics(angles)
            self.last_ik_angles = angles

        self._set_status(f"Reached {label}")

    def handle_input(self, key: int) -> bool:
        """Handle a keypress. Returns False to quit."""
        if key == -1:
            return True

        # --- Quit (ESC always, q/Q only in Joint mode) ---
        if key == 27:
            return False
        if key in (ord('q'), ord('Q')) and self.mode != MODE_CARTESIAN:
            return False

        # --- Tab: switch mode ---
        if key == 9:  # Tab
            self.mode = (self.mode + 1) % NUM_MODES
            self._set_status(f"Mode: {MODE_NAMES[self.mode]}")
            return True

        # --- Torque ---
        if key == ord('t'):
            name = JOINT_NAMES[self.selected_joint]
            mid = StereoBotServo.MOTOR_IDS[name]
            self.torque_on = not self.torque_on
            self.servo.pkt.write1ByteTxRx(
                self.servo.ph, mid, ADDR_TORQUE_ENABLE, 1 if self.torque_on else 0
            )
            self._set_status(f"{name} torque {'ON' if self.torque_on else 'OFF'}")
            return True
        if key == ord('T'):
            self.torque_on = not self.torque_on
            self.servo.set_torque(self.torque_on)
            self._set_status(f"All torque {'ON' if self.torque_on else 'OFF'}")
            return True

        # --- Home / Zero ---
        if key == ord('h'):
            if self.home_raw:
                self._smooth_move_to(self.home_raw, "home")
            else:
                self._set_status("No home_position.json found")
            return True
        if key == ord('0'):
            if self.resting_raw:
                self._smooth_move_to(self.resting_raw, "URDF zero")
            else:
                self._set_status("No resting_position.json found")
            return True

        # --- Mode-specific ---
        if self.mode == MODE_JOINT:
            return self._handle_joint_input(key)
        elif self.mode == MODE_CARTESIAN:
            return self._handle_cartesian_input(key)
        else:
            return self._handle_pid_input(key)

    def _handle_joint_input(self, key: int) -> bool:
        # Select joint
        if ord('1') <= key <= ord('6'):
            self.selected_joint = key - ord('1')
            return True
        if key == curses.KEY_UP:
            self.selected_joint = (self.selected_joint - 1) % 6
            return True
        if key == curses.KEY_DOWN:
            self.selected_joint = (self.selected_joint + 1) % 6
            return True

        # Move joint
        if key == curses.KEY_RIGHT:
            self._move_joint_step(+1)
            return True
        if key == curses.KEY_LEFT:
            self._move_joint_step(-1)
            return True

        # Step size
        if key in (ord('+'), ord('=')):
            self.joint_step = min(200, self.joint_step + 5)
            self._set_status(f"Joint step: {self.joint_step}")
            return True
        if key in (ord('-'), ord('_')):
            self.joint_step = max(1, self.joint_step - 5)
            self._set_status(f"Joint step: {self.joint_step}")
            return True

        # Set current position as URDF zero
        if key == ord('Z'):
            raw = self.servo.read_raw_positions()
            # Save to resting_position.json
            os.makedirs(os.path.dirname(RESTING_PATH), exist_ok=True)
            with open(RESTING_PATH, "w") as f:
                json.dump(raw, f, indent=2)
                f.write("\n")
            # Update internal state
            self.resting_raw = dict(raw)
            self.servo.set_zero_reference(raw)
            # Re-init Cartesian target from new zero
            angles = self.servo.raw_to_relative(raw)
            self.target_4x4 = self.ik.forward_kinematics(angles)
            self._set_status(f"URDF zero saved & applied: {raw}")
            return True

        # Save current position as home
        if key == ord('H'):
            raw = self.servo.read_raw_positions()
            os.makedirs(os.path.dirname(HOME_PATH), exist_ok=True)
            with open(HOME_PATH, "w") as f:
                json.dump(raw, f, indent=2)
                f.write("\n")
            self.home_raw = dict(raw)
            self._set_status(f"Home position saved: {raw}")
            return True

        return True

    def _handle_cartesian_input(self, key: int) -> bool:
        # Translation: WASD = X/Y, QE = Z
        if key == ord('w'):
            self._move_cartesian("x", +1)
        elif key == ord('s'):
            self._move_cartesian("x", -1)
        elif key == ord('a'):
            self._move_cartesian("y", +1)
        elif key == ord('d'):
            self._move_cartesian("y", -1)
        elif key == ord('q'):
            self._move_cartesian("z", +1)
        elif key == ord('e'):
            self._move_cartesian("z", -1)

        # Rotation: IJKL = pitch/yaw, UO = roll
        elif key == ord('i'):
            self._move_cartesian("pitch", +1)
        elif key == ord('k'):
            self._move_cartesian("pitch", -1)
        elif key == ord('j'):
            self._move_cartesian("yaw", +1)
        elif key == ord('l'):
            self._move_cartesian("yaw", -1)
        elif key == ord('u'):
            self._move_cartesian("roll", -1)
        elif key == ord('o'):
            self._move_cartesian("roll", +1)

        # Step size
        elif key in (ord('+'), ord('=')):
            self.cart_trans_step = min(50.0, self.cart_trans_step + 1.0)
            self._set_status(f"Translation step: {self.cart_trans_step:.0f}mm")
        elif key in (ord('-'), ord('_')):
            self.cart_trans_step = max(1.0, self.cart_trans_step - 1.0)
            self._set_status(f"Translation step: {self.cart_trans_step:.0f}mm")
        elif key in (ord(']'),):
            self.cart_rot_step = min(20.0, self.cart_rot_step + 0.5)
            self._set_status(f"Rotation step: {self.cart_rot_step:.1f}deg")
        elif key in (ord('['),):
            self.cart_rot_step = max(0.5, self.cart_rot_step - 0.5)
            self._set_status(f"Rotation step: {self.cart_rot_step:.1f}deg")

        # Reset workspace bounds
        elif key == ord('r'):
            self.workspace_min = np.full(3, np.inf)
            self.workspace_max = np.full(3, -np.inf)
            self._set_status("Workspace bounds reset")

        return True

    def _handle_pid_input(self, key: int) -> bool:
        # Select joint
        if ord('1') <= key <= ord('6'):
            self.selected_joint = key - ord('1')
            return True
        if key == curses.KEY_UP:
            self.selected_joint = (self.selected_joint - 1) % 6
            return True
        if key == curses.KEY_DOWN:
            self.selected_joint = (self.selected_joint + 1) % 6
            return True

        # Select coefficient (Left/Right)
        if key == curses.KEY_LEFT:
            self.pid_selected_coeff = (self.pid_selected_coeff - 1) % 3
            self._set_status(f"Selected: {PID_COEFF_NAMES[self.pid_selected_coeff]}")
            return True
        if key == curses.KEY_RIGHT:
            self.pid_selected_coeff = (self.pid_selected_coeff + 1) % 3
            self._set_status(f"Selected: {PID_COEFF_NAMES[self.pid_selected_coeff]}")
            return True
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

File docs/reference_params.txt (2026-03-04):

======================================================================
  Motor 1: base_yaw
======================================================================

  --- EPROM ---
  Firmware_Major                 addr=0   =     3  (0x0003)  Firmware major version
  Firmware_Minor                 addr=1   =    10  (0x000a)  Firmware minor version
  Model_Number                   addr=3   =   777  (0x0309)  Model number (777=STS3215)
  ID                             addr=5   =     1  (0x0001)  Motor ID
  Baud_Rate                      addr=6   =     0  (0x0000)  Baud rate index (0=1M)
  Return_Delay_Time              addr=7   =     0  (0x0000)  Response delay (x2 us)
  Response_Status_Level          addr=8   =     1  (0x0001)  Status return level
  Min_Position_Limit             addr=9   =     0  (0x0000)  Min position limit
  Max_Position_Limit             addr=11  =  4095  (0x0fff)  Max position limit
  Max_Temperature_Limit          addr=13  =    70  (0x0046)  Max temp limit (C)
  Max_Voltage_Limit              addr=14  =    80  (0x0050)  Max voltage limit (x0.1V)
  Min_Voltage_Limit              addr=15  =    40  (0x0028)  Min voltage limit (x0.1V)
  Max_Torque_Limit               addr=16  =  1000  (0x03e8)  Max torque (0-1000 = 0-100%)
  Phase                          addr=18  =    12  (0x000c)  Phase
  Unloading_Condition            addr=19  =    44  (0x002c)  Unloading condition
  LED_Alarm_Condition            addr=20  =    47  (0x002f)  LED alarm condition
  P_Coefficient                  addr=21  =    24  (0x0018)  PID P gain
  D_Coefficient                  addr=22  =    48  (0x0030)  PID D gain
  I_Coefficient                  addr=23  =     0  (0x0000)  PID I gain
  Minimum_Startup_Force          addr=24  =    16  (0x0010)  Min startup force
  CW_Dead_Zone                   addr=26  =     1  (0x0001)  CW dead zone
  CCW_Dead_Zone                  addr=27  =     1  (0x0001)  CCW dead zone
  Protection_Current             addr=28  =   500  (0x01f4)  Protection current (mA)
  Angular_Resolution             addr=30  =     1  (0x0001)  Angular resolution
  Homing_Offset                  addr=31  raw=0x0445 ( 1093)  decoded=1093
  Operating_Mode                 addr=33  =     0  (0x0000)  Mode (0=pos, 1=speed, 3=step)
  Protective_Torque              addr=34  =    20  (0x0014)  Protective torque (%)
  Protection_Time                addr=35  =   200  (0x00c8)  Protection time
  Overload_Torque                addr=36  =    95  (0x005f)  Overload torque (%)
  Vel_P_Coeff                    addr=37  =    10  (0x000a)  Velocity P coefficient
  Over_Current_Prot_Time         addr=38  =   200  (0x00c8)  Over-current protection time
  Vel_I_Coeff                    addr=39  =   200  (0x00c8)  Velocity I coefficient

  --- SRAM ---
  Torque_Enable                  addr=40  =     0  (0x0000)  Torque enabled
  Acceleration                   addr=41  =   254  (0x00fe)  Acceleration
  Goal_Position                  addr=42  raw=0x07fd ( 2045)  decoded=2045
  Goal_Time                      addr=44  =     0  (0x0000)  Goal time (ms)
  Goal_Velocity                  addr=46  raw=0x0000 (    0)  decoded=0
  Torque_Limit                   addr=48  =   900  (0x0384)  Runtime torque limit (0-1000)
  Lock                           addr=55  =     1  (0x0001)  EPROM lock (1=locked)
  Present_Position               addr=56  raw=0x0801 ( 2049)  decoded=2049
  Present_Velocity               addr=58  raw=0x0000 (    0)  decoded=0
  Present_Load                   addr=60  raw=0x0000 (    0)  decoded=0
  Present_Voltage                addr=62  =    53  (0x0035)  Voltage (x0.1V)
  Present_Temperature            addr=63  =    24  (0x0018)  Temperature (C)
  Status                         addr=65  =     0  (0x0000)  Status flags
  Moving                         addr=66  =     0  (0x0000)  Is moving
  Present_Current                addr=69  =     0  (0x0000)  Current (mA)

  --- FACTORY ---
  Moving_Velocity_Threshold      addr=80  =     1  (0x0001)  Moving velocity threshold
  DTs                            addr=81  =    20  (0x0014)  DTs (ms)
  Velocity_Unit_Factor           addr=82  =    50  (0x0032)  Velocity unit factor
  Hts                            addr=83  =     1  (0x0001)  Hts (ns)
  Max_Velocity_Limit             addr=84  =    68  (0x0044)  Max velocity limit
  Maximum_Acceleration           addr=85  =   254  (0x00fe)  Max acceleration
  Acceleration_Multiplier        addr=86  =     0  (0x0000)  Accel multiplier (when accel=0)
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

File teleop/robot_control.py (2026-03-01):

#!/usr/bin/env python3
"""StereoBot servo interface.

Provides a clean controller class wrapping scservo_sdk for the 6-DOF arm.
Patterns extracted from visualize_urdf.py, servo_test.py, waypoint_nav.py.

Standalone usage:
    python robot_control.py              # read/write round-trip test
    python robot_control.py --save-home  # save current position as home
"""

from __future__ import annotations

import json
import math
import os
import time

import scservo_sdk as scs

# --- Constants ---
STEPS_PER_REV = 4096
STEPS_TO_RAD = 2.0 * math.pi / STEPS_PER_REV
RAD_TO_STEPS = STEPS_PER_REV / (2.0 * math.pi)
POS_SIGN_BIT = 15

# Register addresses
ADDR_TORQUE_ENABLE = 40
ADDR_ACCELERATION = 41
ADDR_GOAL_POSITION = 42
ADDR_GOAL_TIME = 44
ADDR_GOAL_VELOCITY = 46
ADDR_TORQUE_LIMIT = 48
ADDR_PRESENT_POSITION = 56

# SRAM init values
DEFAULT_ACCELERATION = 254
DEFAULT_TORQUE_LIMIT = 900


def decode_sm(raw: int, sign_bit: int) -> int:
    """Decode sign-magnitude register value."""
    magnitude = raw & ((1 << sign_bit) - 1)
    return -magnitude if (raw >> sign_bit) & 1 else magnitude


def encode_sm(value: int, sign_bit: int) -> int:
    """Encode signed integer to sign-magnitude register value."""
    if value >= 0:
        return value & ((1 << sign_bit) - 1)
    return (abs(value) & ((1 << sign_bit) - 1)) | (1 << sign_bit)


class StereoBotServo:
    """Controller for the 6-DOF StereoBot arm servos."""

    JOINT_NAMES = [
        "base_yaw", "shoulder_pitch", "elbow_pitch",
        "wrist_pitch", "wrist_yaw", "camera_roll",
    ]
    MOTOR_IDS = {name: mid for name, mid in zip(JOINT_NAMES, [1, 2, 3, 4, 5, 6])}

    def __init__(self):
        self.ph = None
        self.pkt = None
        self.is_connected = False
        self._goal_sync_write = None
        self._pos_sync_read = None
        # Delta-based encoder unwrapping state
        self._prev_raw: dict[str, int] = {}
        self._unwrapped: dict[str, int] = {}
        self._zero_raw: dict[str, int] = {}

    @classmethod
    def connect(
        cls,
        port: str = "/dev/ttyACM0",
        baudrate: int = 1_000_000,
        urdf_zero: dict[str, int] | None = None,
    ) -> "StereoBotServo":
        """Connect to servos and initialize SRAM registers.

        Args:
            urdf_zero: Absolute encoder positions (steps) corresponding to the
                URDF zero pose (all joints at 0 rad).  When provided,
                read/write_joint_angles operate relative to this reference so
                that ikpy joint limits are correct.  Falls back to connect-time
                readings when not provided.
        """
        self = cls()
        self.ph = scs.PortHandler(port)
        self.pkt = scs.PacketHandler(0)  # protocol version 0 for STS series

        if not self.ph.openPort():
            raise RuntimeError(f"Cannot open {port}")
        if not self.ph.setBaudRate(baudrate):
            self.ph.closePort()
            raise RuntimeError(f"Cannot set baud rate {baudrate}")

        # Verify all motors respond
        for name in cls.JOINT_NAMES:
            mid = cls.MOTOR_IDS[name]
            _, res, _ = self.pkt.ping(self.ph, mid)
            if res != scs.COMM_SUCCESS:
                self.ph.closePort()
                raise RuntimeError(f"Motor {mid} ({name}) not responding")

        # Init SRAM via SyncWrite (2 packets instead of 12 individual writes)
        all_ids = [cls.MOTOR_IDS[n] for n in cls.JOINT_NAMES]
        self._send_sync_write_raw(
            ADDR_ACCELERATION, 1,
            [(mid, DEFAULT_ACCELERATION) for mid in all_ids],
        )
        self._send_sync_write_raw(
            ADDR_TORQUE_LIMIT, 2,
            [(mid, DEFAULT_TORQUE_LIMIT & 0xFF, (DEFAULT_TORQUE_LIMIT >> 8) & 0xFF) for mid in all_ids],
        )

        # GroupSyncRead for bulk position reads (1 USB round-trip instead of 6)
        self._pos_sync_read = scs.GroupSyncRead(self.ph, self.pkt, ADDR_PRESENT_POSITION, 2)
        for mid in all_ids:
            self._pos_sync_read.addParam(mid)

        # Capture initial positions for unwrapping.
        # When urdf_zero is provided, use it as the zero reference so that
        # joint angles match the URDF convention (0 rad = resting pose).
        for name, steps in self._sync_read_positions().items():
            self._prev_raw[name] = steps
            if urdf_zero is not None and name in urdf_zero:
                self._zero_raw[name] = urdf_zero[name]
                delta = steps - urdf_zero[name]
                if delta > STEPS_PER_REV // 2:
                    delta -= STEPS_PER_REV
                elif delta < -STEPS_PER_REV // 2:
                    delta += STEPS_PER_REV
                self._unwrapped[name] = delta
            else:
                self._zero_raw[name] = steps
                self._unwrapped[name] = 0

        # Non-blocking writes for low-latency servo commands
        self.ph.ser.write_timeout = 0

        # Keep SDK SyncWrite for move_to_raw_position (non-latency-critical)
        self._goal_sync_write = scs.GroupSyncWrite(self.ph, self.pkt, ADDR_GOAL_POSITION, 2)

        self.is_connected = True
        return self

    def _send_sync_write_raw(self, start_addr: int, data_len: int,
                              motor_data: list[tuple]) -> None:
        """Send a SyncWrite packet directly to serial, bypassing SDK flush.

        Constructs the raw Feetech protocol v0 packet and writes it without
        calling tcdrain(), reducing latency from ~19ms to <1ms.

        motor_data: list of (motor_id, byte0, byte1, ...) tuples.
        """
        # Packet: FF FF FE LENGTH 83 START_ADDR DATA_LEN [ID D...]×N CHECKSUM
        n_motors = len(motor_data)
        n_params = 2 + n_motors * (1 + data_len)  # start_addr + data_len + per-motor
        length = n_params + 2  # instruction + params + checksum
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

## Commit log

2026-02-26 add first urdf & STL 3d print files
    [Baseplate.stl, CamBot_Baseplate.stl, CamBot_Link1.stl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]
2026-02-26 Rename to StereoBot, add README, fix URDF joint axes and limits
    - Rename cambot.urdf to stereobot.urdf, update all references
    - Invert joint axes for base_yaw, shoulder_pitch, wrist_yaw, camera_roll
    - Update joint limits from calibration measurements
    - Change camera_yaw to camera_roll (rotation around X, not Z)
    - Add encoder overflow unwrapping in calibrate_limits.py and visualize_urdf.py
    - Add concise README.md
    [stereobot.urdf]
2026-02-27 Add teleop system for VR head tracking and servo control
    WebXR Quest 3 client streams head pose over WebSocket to aiohttp server,
    which runs IK via ikpy/URDF and drives Feetech STS3215 servos. Includes
    ZED Mini stereo capture with fallback for testing.
2026-02-27 Fix URDF zero reference mismatch for correct IK joint limits
    The resting pose (all joints at 0°) is now the zero reference for joint
    angles, matching the URDF convention. Previously, connect-time encoder
    readings were used as zero, causing ikpy joint limits to be shifted
    relative to the actual physical range.
    StereoBotServo.connect() accepts an optional urdf_zero parameter
    (absolute encoder steps for the URDF zero pose). TeleHead loads the
    resting position JSON and passes it as urdf_zero.
    Also includes pre-existing working-tree changes: SyncRead/SyncWrite
    bulk I/O, cosine easing for smooth moves, single-packet set_torque.
    [robot_control.py, telehead.py]
2026-02-28 Replace hardcoded PID tuning poses with user-defined capture system
    Hardcoded EXTENDED/HOME poses caused the arm to crash into the table.
    Now users physically position the robot and capture safe poses with
    --capture-poses. Also fixes safety check triggering prematurely on
    large step sizes by using divergence-based threshold.
    - Remove EXTENDED_RAW, JOINT_TEST_CONFIG, step_sign, HOME waypoint logic
    - Add capture_poses() interactive flow and load_tuning_poses()
    - Rewrite evaluate_pid() to iterate over user-defined pose pairs
    - Safety limit now relative to step size: initial_distance + margin
    - Add --capture-poses and --poses-file CLI flags
    - Validate >=2 poses per joint before tuning starts
    C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
    [pid_tuning.py]
2026-03-01 Add servo velocity profiling mode and debug_control calibration keys
    Add optional use_servo_time_profile to move_to_raw_position() that uses
    per-motor velocity-limited SyncWrite instead of host-side cosine
    interpolation. Add --servo-profile CLI flag to debug_control.py.
    Add H/Z keys in joint mode to save home/URDF-zero positions to
    calibration JSON and update internal state live. Fix roll axis Z+/-
    key mapping (u/o swapped).
    [debug_control.py, robot_control.py]
2026-03-01 Add frame drop fix, latency tracking, and VR controls
    Replace buffer-based frame dropping with adaptive time-based dropping
    that works correctly with SSL/TLS transport. Add 16-byte binary frame
    header (magic, seq, capture_ts) for end-to-end timing.
    Server: ping/pong RTT measurement (EMA), telemetry broadcast (2s),
    command handling for calibrate/toggle_position from VR client.
    Client: frame header unpacking, VR HUD (head-locked status bar with
    calibration state, position mode, RTT, FPS, controller hints),
    Quest controller button mapping (A/X=calibrate, B/Y=position toggle),
    DOM buttons for non-VR testing.
    Capture: thread-safe capture timestamps on both ZED and fallback paths.
    TeleHead: exp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
    [server.py, telehead.py]
2026-03-01 Improve VR display settings and fix resolution switch crash
    - Replace size slider with FOV slider (computes screen size from distance + FOV)
    - Add Screen Y and HUD Y position sliders for Quest lens tuning
    - Move HUD to fixed 0.5m distance with opaque background and vergence grid
    - Default to dist=2.5m, fov=90° matching ZED Mini horizontal FOV
    - Fix resolution switch segfault: stop capture loop and join thread
    before closing ZED device to prevent use-after-free in native SDK
    [telehead.py]
2026-03-01 Add servo CLI tools, IK improvements, and streaming backpressure
    Servo tools:
    - fix_servo_ids.py: add --scan, --set-id, --from-id CLI modes
    - read_all_params.py: add --write mode with EPROM safety, --motors filter
    IK solver:
    - Add camera midpoint tip link for accurate end-effector targeting
    - Add neck-pivot correction to remove eye arc from VR rotation
    - Add direct solve_orientation (Euler decomposition, no IK needed)
    - Periodic FK validation to reduce CPU overhead at 100Hz
    - Extract and clamp joint limits from URDF
    Server:
    - RTT-based backpressure to prevent bufferbloat on slow links
    - Shared frame event surviving capture object swaps
    - Resolution switching protocol with broadcast notific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
    [fix_servo_ids.py, ik_solver.py, server.py]
2026-03-01 Fix calibration pose capture and add pyproject.toml
    Calibration fix:
    - Pause control loop for entire calibration sequence, not just the
    home move, preventing servo jumps from stale neutral pose
    - Run calibration as background async task so WebSocket receive loop
    keeps processing head poses during the 2s home move (was blocking
    the receive loop, starving pose updates)
    - Wait for fresh VR pose after move completes before capturing neutral
    Project setup:
    - Add pyproject.toml with dependency management (numpy, ikpy, scipy,
    aiohttp, opencv-python, feetech-servo-sdk, optional zed/viser)
    Also includes WebRTC scaffolding and zed_capture raw frame access.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
    [server.py, telehead.py]
2026-03-01 Restructure repo into proper cambot Python package
    Eliminate massive code duplication (decode_sm in 6 files, register constants
    in 8 files, connect() in 5 files) by creating a shared servo communication
    layer. Move all code into a cambot/ package with clear separation:
    - cambot/servo/ — shared constants, protocol helpers, StereoBotServo controller
    - cambot/teleop/ — VR teleop app (was teleop/)
    - cambot/tools/ — CLI diagnostic/setup tools (were root scripts + teleop utils)
    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
    [ST3215 memory register map-EN.xls]
2026-03-01 Fix VR HUD toggle and improve HUD readability
    Fix grip button index (2→1) so HUD toggle actually fires on Quest 3,
    lower default HUD position to -0.4, and tilt the quad to face the eye
    center for better readability at lower positions.
2026-03-01 Center VR HUD using eye midpoint instead of left-eye position
    Three.js r169 ArrayCamera copies its matrixWorld from the left eye
    camera, offsetting head-locked elements by half the IPD. Compute the
    true head center by lerping between both eye positions for the HUD.
2026-03-01 Add safety bounding box, position delta limit, and pose watchdog
    Three safety features for position tracking mode:
    - Workspace bounding box (--workspace-bounds): clamps EE to axis-aligned box
    - Max position delta sphere (--max-pos-delta): limits displacement from home
    (default 0.15m, auto-disabled when workspace-bounds is set)
    - Pose watchdog (--watchdog-timeout): returns to home if VR data stops for
    3s (handles headset removal/disconnect)
2026-03-02 Add headset-off detection, soft recalibration, and smooth position toggle
    Instantly triggers watchdog return-to-home when XR session ends or page
    becomes hidden, instead of waiting for the 3s timeout. Adds calibrate_soft()
    for instant recalibration without servo movement (current position becomes
    new home). Position tracking toggle now soft-recalibrates before switching
    off to prevent joint snap.
    [app.py, server.py]
2026-03-02 Fix position toggle race condition, headset detection, and watchdog resume
    - Add atomic toggle_position_tracking() that holds the _moving_to_position
    gate across both recalibration and toggle, preventing the control loop
    from seeing a half-updated state between the two operations
    - Fix calibrate_soft() to use _smoothed_q instead of servo reads, avoiding
    serial bus conflicts with the control loop thread
    - Fix headset-off detection: use XR session visibilitychange event instead
    of document visibilitychange (Quest 3 proximity sensor doesn't fire
    sessionend when headset is removed)
    - Auto-recalibrate when watchdog clears (headset put back on) so robot
    starts cleanly from home positio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
    [app.py, server.py]
2026-03-02 Set aiohttp shutdown timeout to 1s to fix double Ctrl+C requirement
    The default 60s shutdown_timeout causes aiohttp to wait for active
    WebSocket connections to close gracefully, requiring a second Ctrl+C.
    [app.py]
2026-03-02 Add CPU idle mode, smooth watchdog return, user pause, and WebRTC fixes
    - Camera capture idles when no video clients connected (demand-based)
    - Control loop uses adaptive sleep (1Hz idle vs 100Hz active)
    - Watchdog return-to-home uses 1 rad/s with exponential deceleration
    instead of 3 rad/s constant (was perceived as instant/max speed)
    - Watchdog skips servo writes and sleeps when already at home
    - User pause (lock/unlock robot) via L key, right squeeze, or UI button
    - WebRTC: fix small placeholder frame activation, drift reset, close
    all peers on new offer to prevent stale encoders
    [app.py, server.py]
2026-03-02 Fix exit-VR frozen frame and flickering FPS display
    - Exit VR now sends pause with keep_video flag so 2D web page
    continues showing live frames instead of freezing on last frame
    - Remove render-loop FPS counter that was racing with WebRTC stats
    API, causing FPS display to alternate between 90 and 30
    [server.py]
2026-03-03 add latest 3d model changes
    [Baseplate.stl, CamBot_Baseplate.stl, CamBot_Link1.stl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]
2026-03-03 Rename StereoBot to CamBot, add build guide and set_pid tool, prune unused tools
    - Rename StereoBot -> CamBot across all modules, classes, and URDF
    - Add docs/BUILD_GUIDE.md with parts list, 3D printing, motor config,
    assembly, calibration, and PID tuning instructions
    - Add cambot/tools/set_pid.py to write tested PID parameters to servos
    - Add run_set_pid.sh wrapper and pyproject.toml entry point
    - Remove unused tools: servo_test, servo_offset, calibrate_limits,
    waypoint_nav (superseded by debug_control or no longer needed)
    - Update README with CamBot image, build guide link, and pruned tool list
    [cambot.urdf]
2026-03-03 Add VR controls documentation, simplify shell wrappers to use uv entry points
    - Document all terminal keyboard and Quest 3 controller commands in README
    - Note Linux-only testing and link to uv installation docs
    - Simplify run_*.sh scripts from `uv run python -m ...` to `uv run cambot-...`
    - Add missing cambot-visualize-urdf entry point to pyproject.toml
2026-03-04 Add torque protection to set_pid, home pose photo, and reference params
    - set_pid.py: write Overload_Torque=95 for motors 1-5 and
    Max_Torque_Limit=500 for camera_roll alongside PID values
    - BUILD_GUIDE: inline URDF zero and home pose images, document torque
    settings, link to reference_params.txt, use uv run for pid-tuning
    - Add docs/reference_params.txt with full register dump for comparison
    - Add 3dprint/CamBot_HomePose.jpg showing example home pose
    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
    [ST3215 memory register map-EN.xls, reference_params.txt]
2026-03-05 Add base plate 3d models with 40 mm distance boreholes for M5 screws
    [Baseplate.stl, CamBot_Baseplate.stl, CamBot_v2.3mf]
